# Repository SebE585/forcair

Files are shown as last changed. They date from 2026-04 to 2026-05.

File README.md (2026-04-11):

# Forcair

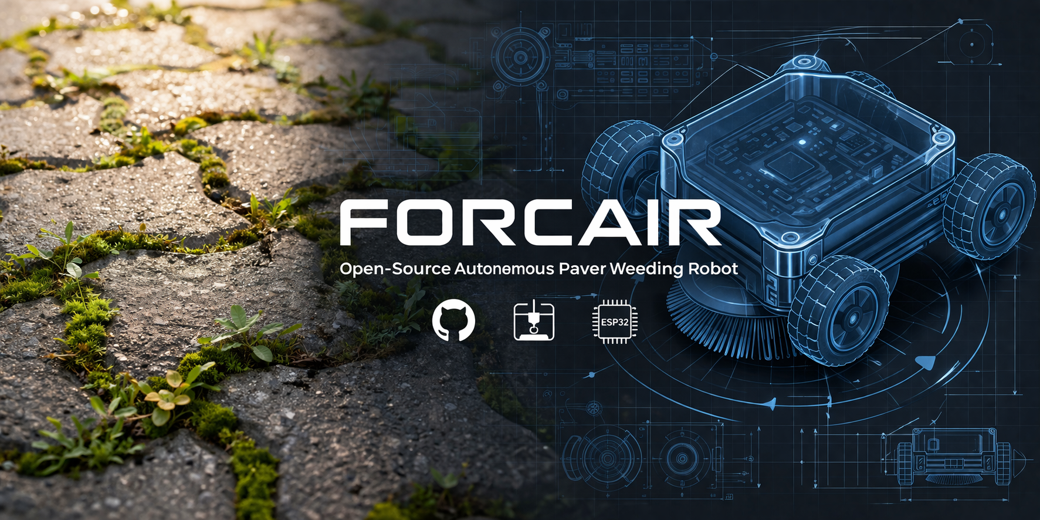
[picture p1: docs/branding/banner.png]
Forcair Banner


**The open-source robot that cleans your patio while you relax.**

Forcair is a low-cost, open-source autonomous robot that removes moss and weeds from paved surfaces using a rotating brush and computer vision.

Built with aluminum extrusion profiles, 3D printed parts, and an ESP32-CAM. Under 1.3 kg. ~150 EUR from scratch (or ~75 EUR if you reclaim motors + battery + brush motor from junk).

> Named after a vehicle from [*Jayce and the Wheeled Warriors*](https://en.wikipedia.org/wiki/Jayce_and_the_Wheeled_Warriors) (1985).

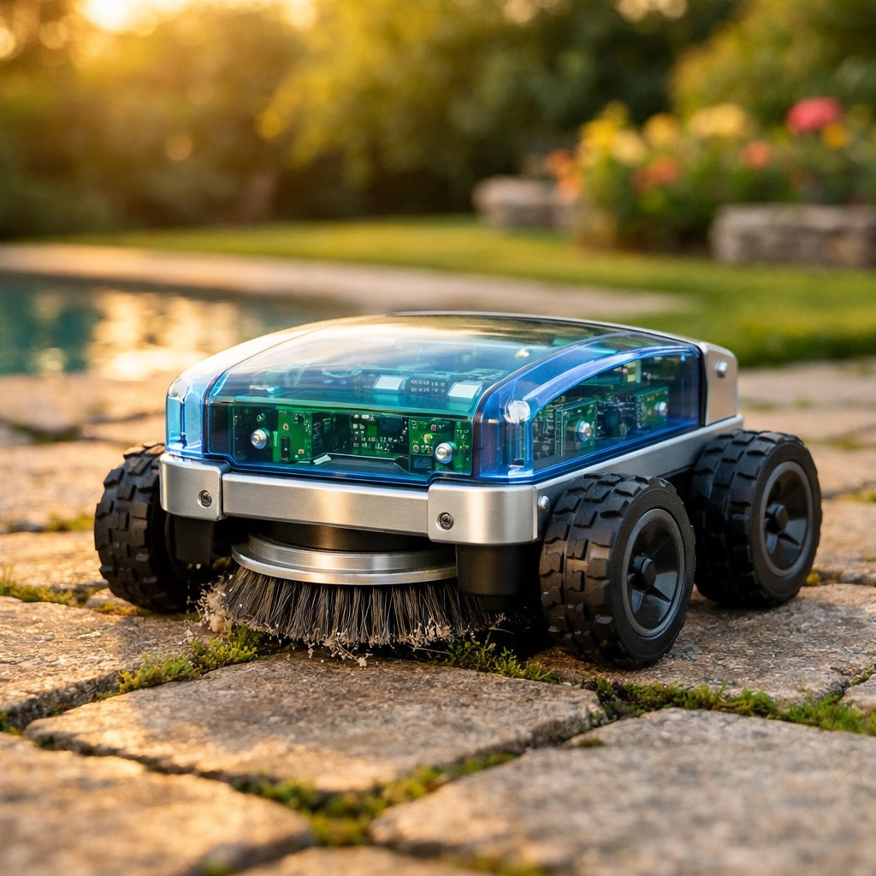
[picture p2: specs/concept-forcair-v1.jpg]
Concept


---

## The Problem

Interlocking pavers and stone patios accumulate **moss and weeds** in their joints. Existing solutions:

| Solution | Cost | Effort | Eco-friendly |
|---|---|---|---|
| Manual scraping | 0 EUR | Hours on your knees | Yes |
| Pressure washer | 200+ EUR | Heavy, damages joints | Wastes water |
| Chemical herbicide | 10 EUR/year | Easy | **No** |
| Commercial robot mower | 1000+ EUR | N/A on pavers | N/A |
| **Forcair** | **~150 EUR** (or ~75 EUR with reclaimed parts) | **Autonomous** | **Yes** |

## How It Works

| Step | What | How |
|---|---|---|
| **1. Detect** | ESP32-CAM sees green moss on gray pavers | HSV color thresholding (no cloud, on-device) |
| **2. Navigate** | Bump & turn — or systematic sweep on ~150 m² | Phase 1.5 reactive → Phase 2 IMU dead reckoning → Phase 3 GPS RTK |
| **3. Clean** | Rotating brush scrubs the joint | Nylon or steel wire, ~50 mm disc, drill-style attachment |

The robot patrols your patio autonomously. When the camera detects green moss, it lowers the rotating brush and scrubs the joint clean. Simple, mechanical, effective.

## Specifications

| Parameter | Value |
|---|---|
| Dimensions | 300 x 250 x 100 mm |
| Weight | ~1.3 kg |
| Frame | Aluminum 2020 extrusion profiles |
| Wheels | 4x 80mm (PETG hub + TPU tire), 4WD |
| Brain | ESP32-CAM (camera + WiFi + GPIO) |
| Motor driver | L298N dual H-bridge (2 A/ch, PWM + IN1/IN2) ×2 |
| Brush | Rotary nylon or steel wire, 50mm, on Z-axis |
| Battery | 3S 18650 pack (11.1V), ~1h15 autonomy |
| Navigation | Bump & turn (Phase 1) → IMU dead reckoning (Phase 2) → GPS RTK (Phase 3) |
| Detection | HSV green-on-gray thresholding (inspired by [OWL](https://github.com/geezacoleman/OpenWeedLocator)) |
| Manufacturing | 3D printing (Bambu Lab X1C) + off-the-shelf parts |
| **Total cost** | **~150 EUR** from scratch, all-in (or ~75 EUR if you reclaim motors + battery + brush motor) — see [live BOM widget](https://sourcier.shop/bom/SebE585/forcair) |

## Project Status

| Phase | Status | Description |
|---|---|---|
| **Phase 0** | **In progress** | Manual brush testing (drill + brush on pavers) |
| Phase 1 | Planned | Wheeled base + ESP32-CAM scout + remote control |
| Phase 1.5 | Planned | Bump & turn by zones (~30m² per session) |
| Phase 2 | Future | Systematic sweep with IMU dead reckoning (MPU6050) for 150m² |
| Phase 3 | Future | GPS RTK (u-blox F9P + NTRIP) for full autonomous coverage |

## Build Your Own

### Bill of Materials (BOM)

The BOM is maintained as a machine-readable [`BOM.yaml`](BOM.yaml) at the root of this repo
and consumed by [sourcier.shop](https://sourcier.shop) to generate a live, always-up-to-date
sourcing widget with vendor links optimized per country.

> 🛒 **Live BOM widget:** [**sourcier.shop/bom/SebE585/forcair**](https://sourcier.shop/bom/SebE585/forcair)
>
> One click to see all 27 components, vendor matches (Motedis, AliExpress, Leroy Merlin…),
> per-line and total estimated cost, with country-aware vendor selection (FR/DE/UK/US).
> Supports `?lang=fr|en` for multilingual descriptions.

The BOM is organized in 5 supply lanes:

- **A — AliExpress**: electronics + small mechanical hardware (bearings, drivers, sensors, connectors, screws)
- **B — Motedis**: aluminum 2020 extrusion (custom-cut profiles, corner brackets, T-nuts)
- **C — Bambu Lab Store**: filament (PETG translucent blue dome + TPU 95A tires + PETG black chassis)
- **D — Hardware store / Brico**: plywood platform, drill brushes, PG7 cable glands, foam seals
- **E — Reclaimed from junk**: see table below — these items are not in the public BOM since they
  depend on what donors you can find locally

Need to add a vendor or update a price? Edit [`BOM.yaml`](BOM.yaml) and Sourcier will pick it up
within 1 hour (cache TTL). The BOM.yaml format spec is documented at
[sourcier.shop/spec/bom-yaml](https://sourcier.shop/spec/bom-yaml).

#### Reclaimed from junk — project-specific (not in BOM.yaml)

| Part | Source | Notes |
|---|---|---|
| 4× DC traction motors | Old inkjet printers | Canon MG6450, Epson XP-2150 |
| ESP32-CAM | Stock | Phase 1 brain |
| RPi Zero 2W | Stock | Phase 2 vision |
| GoPro Hero 3+ | Stock | Phase 2 mapping |
| 8 mm linear rods (Z-axis) | Old printers | 2× recovered |
| 12 V brush motor | Reclaimed vacuum (Telsa 80) | or ~5 EUR if no donor |
| 3S 18650 battery pack | Reclaimed Ryobi 36V | or ~15 EUR new pack |
| Springs (Z-axis return) | Old printers | Multiple |

#### 3D printed parts — free (you supply filament from supply lane C)

| Part | Material | Print time | Notes |
|---|---|---|---|
| 4× wheel hubs | PETG black | ~1 h each | 608ZZ housing |
| 4× tires | TPU 95A black | ~45 min each | Striped tread |
| 4× motor mounts | PETG black | ~30 min each | 2020 cradle |
| Brush Z-axis carriage | PETG black | ~2 h | IMS-002 |
| 2× linear bearings | PETG black | ~15 min each | 8 mm rods |
| **Dome cover** | **PETG translucent blue** | ~3 h | The signature shell, PCBs visible through |
| ESP32-CAM mount | PETG black | ~15 min | + tilt adjustment |
| Brush confinement skirt | TPU 95A black | ~45 min | Soft seal under chassis |
| Front bumper | TPU 95A black | ~30 min | Integrates micro-switches |
| IR sensor mount (front) | PETG black | ~15 min | |
| 2× cliff sensor mounts | PETG black | ~10 min each | |

### Total budget (Phase 1.5 functional)

| Lane | Cash |
|---|---|
| A — AliExpress (electronics + mechanical) | ~55 EUR |
| B — Motedis (custom-cut extrusion) | ~20 EUR |
| C — Bambu Lab (filament dedicated to Forcair) | ~30 EUR |
| D — Brico (plywood, brushes, seals, PG7) | ~18 EUR |
| E — Reclaimed parts | 0 EUR |
| Shipping & misc | ~10 EUR |
| **Total cash, all-in** | **~135-155 EUR** |
| Total saved by reclaiming (vs new) | ~50 EUR |

The original "<75 EUR" target on the project banner refers to the bare-minimum Phase 1
electronics-only build assuming all reclaimable parts are available (motors, battery, brush motor,
linear rods). Real-world cost for a from-scratch build sits closer to **~150 EUR** including
filament and shipping. See the live [Sourcier widget](https://sourcier.shop/bom/SebE585/forcair)
for the up-to-date estimate based on current vendor prices.

### CAD Files

All mechanical parts are parametric, written in [CadQuery](https://cadquery.readthedocs.io/) (Python).
STEP and STL exports are provided for direct slicing.

```
hardware/cad/
├── assembly_chassis.py      # Full assembly visualization
├── wheel_hub.py             # PETG wheel hub (WH-001)
├── wheel_tire.py            # TPU tire (WT-001)
├── motor_mount.py           # Motor cradle for 2020 profile
├── ims_plate.py             # Interchangeable Module Standard plate
├── mod002_brosse.py         # Rotating brush module (MOD-002)
├── esp32_cam_mount.py       # ESP32-CAM bracket with tilt
├── capot_dome.py            # Protective dome (PETG translucent blue)
├── step/                    # STEP exports
└── stl/                     # STL exports (ready to print)
```

### Printing Guide

| Part | Material | Infill | Pattern | Perimeters | Layer | Time |
|---|---|---|---|---|---|---|
| Wheel hubs (x4) | PETG | 40% | gyroid | 4 | 0.2mm | ~45min each |
| Tires (x4) | TPU 95A | 20% | gyroid | 3 | 0.2mm | ~40min each |
| Motor mounts (x4) | PETG | 40% | gyroid | 4 | 0.2mm | ~25min each |
| Dome cover | PETG (translucent blue) | 15% | gyroid | 3 | 0.2mm | ~3h |
| All other parts | PETG | 30-40% | gyroid | 3 | 0.2mm | varies |
| **Total Phase 1** | | | | | | **~10-11h** |

**Why not 100% infill on wheels and tires?**

- **Wheel hubs (PETG, 40% gyroid)** — for a 1.3 kg robot (~330 g per wheel), radial and torsional loads are carried by the perimeters, not the infill. 4 walls + 40% gyroid is plenty; 100% just wastes filament and print time without measurable benefit.
- **Tires (TPU 95A, 20% gyroid)** — the whole point of TPU is compliance (grip + shock absorption). Printing TPU at 100% gives a *rigid* rubber tire with no give, which actively defeats the purpose: less grip on uneven pavers, more vibration into the chassis. 15-25% gyroid keeps the tire deformable enough to conform to joints while staying durable.

## Research & State of the Art

See [`research/state-of-the-art.md`](research/state-of-the-art.md) for a comprehensive literature review covering:

- 12+ similar DIY/open-source projects analyzed
- 24 scientific papers reviewed
- Validation of the rotating brush approach on hard surfaces ([Rask & Kristoffersen 2007](https://doi.org/10.1111/j.1365-3180.2007.00579.x))
- Identified gap: **no published work on autonomous robotic weeding for domestic paved surfaces**

Key references:
- [OpenWeedLocator (OWL)](https://github.com/geezacoleman/OpenWeedLocator) - green-on-brown detection algorithm we adapt to green-on-gray
- [Tertill](https://tertill.com/) (discontinued) - bump & turn navigation validated for small surfaces
- [LIAM-ESP](https://github.com/trycoon/liam-esp) - ESP32 navigation code reference

## Modular Tool System (IMS)

Forcair uses an **Interchangeable Module Standard** (IMS) interface — a single 100×80 mm plate
with a fixed mechanical and electrical pinout. Modules clip on tool-free in ~30 seconds.

**IMS Plate spec** (100 × 80 mm):

| Feature | Spec | Purpose |
|---|---|---|
| Fixation | 2× M5 butterfly bolts | Tool-free swap in ~30 s |
| Alignment | 2× centering posts, ⌀ 8 mm | Repeatable positioning |
| Power | XT60 connector | 12 V, 10 A continuous |
| Signal | JST-XH 3-pin | PWM control + ground |

| Module | Function | Status |
|---|---|---|
| MOD-002 | Rotating brush (nylon/steel) | Phase 1.5 |
| MOD-001 | Camera scout (GoPro) | Phase 2 |
| MOD-003 | Spray (water or anti-moss) | Future |
| MOD-004 | Leaf blower | Future |

Design your own module! The IMS plate CAD file is in `hardware/cad/ims_plate.py`.

## Architecture

**Phase 1.5 — ESP32-CAM only** (~150 EUR from scratch / ~75 EUR with reclaimed parts):

```mermaid
graph LR
    Phone["📱 Smartphone<br/>(monitoring)"]
    ESP["ESP32-CAM<br/>OV2640 + HSV detect<br/>GPIO control"]

    Sensors["2× Sharp IR (front)<br/>2× TCRT5000 (cliff)<br/>2× microswitch (bumper)<br/>1× piezo buzzer"]
    Servo["SG90 servo<br/>(Z-axis brush lift)"]
    Traction["2× L298N H-bridge<br/>↓<br/>4× DC motors"]
    Brush["IRLZ44N MOSFET<br/>↓<br/>12 V brush motor"]

    Phone <-. WiFi .-> ESP
    ESP --> Sensors
    ESP --> Servo
    ESP --> Traction
    ESP --> Brush
```

**Phase 2** (+2 EUR) — add an MPU6050 IMU for dead-reckoning navigation, enabling systematic
line sweeps over ~150 m².

**Phase 3** (+40 EUR) — add a u-blox F9P GPS-RTK receiver with NTRIP corrections for
centimeter-level outdoor positioning and full coverage planning.

## Contributing

Contributions welcome! Here's how you can help:

- **Build one** and share your results (especially with different paver types)
- **Improve the firmware** (ESP32 Arduino or ESP-IDF)
- **Design new modules** for the IMS interface
- **Test different brushes** and document effectiveness vs. joint wear
- **Translate** documentation
- **Report issues** or suggest improvements

## License

- **Hardware** (CAD, mechanical design): [CERN-OHL-S v2](LICENSE-HARDWARE)
- **Software** (firmware, scripts): [MIT](LICENSE-SOFTWARE)
- **Documentation**: [CC BY-SA 4.0](https://creativecommons.org/licenses/by-sa/4.0/)

## Related Projects

Forcair is part of a family of DIY projects, all named after vehicles from *Jayce and the Wheeled Warriors*:

| Project | Description |
|---|---|
| **Forcair** | Autonomous paver weeding robot (this project) |
| Vrillair | DIY CNC machine |
| Blindair | Modular workshop storage boxes |
| Depistair | Reclaimed parts inventory & shared BOM |

## Acknowledgments

- [OpenWeedLocator](https://github.com/geezacoleman/OpenWeedLocator) for the green-on-brown detection approach
- [Tertill](https://tertill.com/) (Franklin Robotics) for proving bump & turn works
- [LIAM-ESP](https://github.com/trycoon/liam-esp) for ESP32 navigation patterns
- The scientific work of Rask & Kristoffersen (2007) and Cauwer et al. (2014) on non-chemical weed control on hard surfaces

---

*Forcair is a personal open-source project. Not affiliated with any company.*

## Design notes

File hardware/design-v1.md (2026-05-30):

# Forcair - Design Chassis v1.2

> Plateforme robotique modulaire d'exterieur pour entretien des paves.
> Version : v1.2 - 2026-04-17 (guides Z flex Ø6/Ø8 + axes roue explicites)
> Version precedente : v1.1 - 2026-04-03
> Image concept : `../specs/concept-forcair-v1.jpg`
> Etat de l'art : `../research/state-of-the-art.md`

## 0. Architecture modulaire

Forcair est une **plateforme** (base roulante + electronique + vision) sur laquelle
se montent des **modules outils** interchangeables via une interface standard.

```
         PLATEFORME FORCAIR (base commune)
    ┌──────────────────────────────────────────┐
    │  Chassis 2020 + 4WD + ESP32 + RPi + Bat  │
    │  Navigation + Vision + WiFi              │
    └─────────────────────┬────────────────────┘
                          │
                 Interface Module Standard
                 (2x vis papillon M5 + XT60)
                          │
        ┌─────────────────┼─────────────────┐──── ...
        │                 │                 │
   ┌────┴────┐      ┌─────┴─────┐     ┌────┴────┐
   │ MOD-001 │      │  MOD-002  │     │ MOD-003 │
   │ CAMERA  │      │  BROSSE   │     │  SPRAY  │
   │ SCOUT   │      │ ROTATIVE  │     │         │
   │         │      │           │     │ Jet eau │
   │ Carto + │      │ Mousse /  │     │ ou anti │
   │ inspect │      │ herbes    │     │ mousse  │
   │         │      │           │     │         │
   │ Phase 1 │      │ Phase 2   │     │ Futur   │
   └─────────┘      └───────────┘     └─────────┘
```

### Interface Module Standard (IMS)

L'interface entre la plateforme et les modules est le point cle de la modularite.
Elle se situe sur le **chariot Z** (mecanisme montee/descente).

```
     VUE DE FACE - Interface Module Standard

     ┌──────────── chariot Z ────────────┐
     │                                    │
     │  ⊙ vis papillon     vis papillon ⊙ │  ← M5, serrage a la main
     │       M5                  M5       │
     │                                    │
     │       ┌──── plot ────┐             │
     │       │  centrage    │             │  ← 2 plots de centrage (imprimes 3D)
     │       └──────────────┘             │     garantissent l'alignement
     │                                    │
     │    [XT60]        [JST-XH 3p]       │  ← connecteurs : alim + signal
     │    alim 12V      signal PWM        │
     │                                    │
     └────────────────────────────────────┘
               ↕ interchangeable ↕
     ┌────────────────────────────────────┐
     │         MODULE (ex: brosse)        │
     │                                    │
     │  ⊙ trou M5           trou M5 ⊙    │
     │       ┌──── trou ────┐             │
     │       │  centrage    │             │
     │       └──────────────┘             │
     │    [XT60]        [JST-XH 3p]       │
     │                                    │
     │         [outil]                    │
     └────────────────────────────────────┘
```

### Specs interface

| Parametre | Valeur | Notes |
|---|---|---|
| Fixation mecanique | 2x vis papillon M5 | Serrage/desserrage a la main, pas d'outil |
| Centrage | 2x plots diam 8mm | Imprimes 3D, positionnement reproductible |
| Alimentation | Connecteur XT60 | 12V, 10A max (suffisant pour moteur brosse) |
| Signal | Connecteur JST-XH 3 broches | PWM vitesse + GND + sens rotation |
| Dimensions plaque module | 100 x 80 mm | Standard pour tous les modules |
| Masse max module | 500g | Budget masse restant sur chariot Z |

### Catalogue modules (prevu)

| Ref | Nom | Contenu | Statut |
|-----|-----|---|---|
| MOD-001 | Camera Scout | GoPro Hero 3+ sur support orientable | Phase 1 |
| MOD-002 | Brosse Rotative | Moteur Telsa 80 + brosse nylon | Phase 2 |
| MOD-003 | Spray | Pompe 12V + reservoir + buse | Futur |
| MOD-004 | Souffleur | Ventilateur 12V centrifuge | Futur |
| MOD-005 | Balai | Brosse douce large | Futur |

## 1. Contraintes terrain

Donnees extraites des photos (`specs/photos/`) :

| Contrainte | Valeur | Impact design |
|---|---|---|
| Type paves (terrasse) | Autobloquants, joints ~10mm | Roues > 60mm diam, pas trop fines |
| Type dalles (allee) | Carrees ~30x30cm, joints ~8mm | Surface plus reguliere |
| Mousse | Dans les joints, epaisseur 2-5mm | Brosse doit atteindre le fond du joint |
| Denivele joints | 3-8mm entre paves | Suspension ou roues souples |
| Surface totale | **~150m2** (terrasse + allees + abords piscine) | Navigation par zones ou systematique necessaire |
| Environnement | Exterieur, humidite, soleil | Electronique protegee |
| Obstacles | Bordures pierre, pieds de table, mur | Detection ou bumper |

## 2. Dimensions generales

```
     VUE DE DESSUS (cotes en mm)

     ←──────── 300 ─────────→

  ↑  ┌─profilé 2020─────────────profilé 2020─┐
  │  │                                        │
  │  │  ┌──────────────────────────────────┐  │
     │  │          ZONE ELECTRONIQUE       │  │
 250 │  │  [ESP32-CAM]       [RPi Zero 2W] │  │
     │  │  [Motor driver]    [Batterie 3S] │  │
  │  │  └──────────────────────────────────┘  │
  │  │                                        │
  │  │  ┌──────────────────────────────────┐  │
  ↓  │  │          ZONE ACTIONNEUR         │  │
     │  │  [Moteur brosse]   [Mecanisme Z] │  │
     │  └──────────────────────────────────┘  │
     └────────────────────────────────────────┘
    ◯roue AR-G                        roue AR-D◯

    ◯roue AV-G                        roue AV-D◯
```

| Parametre | Valeur | Justification |
|---|---|---|
| Longueur (X) | 300 mm | Couvre 2-3 paves en largeur |
| Largeur (Y) | 250 mm | Stabilite + place pour electronique |
| Hauteur chassis | ~100 mm | Garde au sol ~30mm + plateau + composants |
| Garde au sol | 30 mm | Passer les irregularites entre paves |
| Poids cible | < 2.5 kg | Moteurs recup DC suffisants |
| Empattement roues | 260 x 210 mm | Stabilite sur surface irreguliere |

## 3. Structure chassis

### 3.1 Cadre en profiles 2020

```
     VUE DE DESSUS - CADRE

     ┌═══════════════════════════════════┐
     ║           traverse AV            ║  ← profilé 250mm
     ╠═══════════════════════════════════╣
     ║                                   ║
     ║  longueur G          longueur D   ║  ← profilés 300mm
     ║                                   ║
     ╠═══════════════════════════════════╣
     ║           traverse AR            ║  ← profilé 250mm
     └═══════════════════════════════════┘

     Assemblage : 4x equerres 20x20 Motedis (1 par angle)
```

**Decoupe dans les barres Motedis 1m :**
- Barre 1 : 300 + 300 + 250 + 100(reste) = 1 barre
- Barre 2 : 250 + reste pour Vrillair

**Fixation equerres :** ecrou marteau M4 + vis M4x8 (kit Motedis)

### 3.2 Plateau

Le plateau se fixe sur les profiles via T-nuts M5.

| Option | Materiau | Epaisseur | Poids | Waterproof | Recommandation |
|---|---|---|---|---|---|
| A | Contreplaque | 5mm | ~150g | Non (vernis possible) | **Proto Phase 1** |
| B | **PETG noir imprime** | 2-3mm | ~120g | Oui | **Version finale** (cf image concept) |
| C | Plaque inox Silvercrest | 1-2mm | ~200g | Oui | Alternative (decoupe necessaire) |
| D | Polypropylene alveolaire | 4mm | ~50g | Oui | Trop souple seul |

**Phase 1 : contreplaque 5mm** (280 x 230 mm), perce aux emplacements T-nuts.
**Version finale : PETG noir** imprime en plusieurs pieces, assemblee par clips/vis.

### 3.3 Protection electronique / Carrosserie

> Ref visuelle : `../specs/concept-forcair-v1.jpg`
> Objectif : capot translucide bleu laissant voir les PCB (effet "tech visible").

L'electronique doit etre protegee (usage exterieur, projections d'eau/mousse).

```
     VUE DE COTE - CAPOT

          ┌──capot PETG imprime──┐
          │                      │
     ─────┤   [electronique]     ├─────  plateau
          │                      │
          └──────────────────────┘
```

**Phase 1 (proto) :**
- Capot imprime en PETG gris/naturel
- Fixation par clips sur le plateau (pas de vis = demontage rapide)
- Ouvertures pour ventilation (labyrinthes anti-projection)
- Passage cables etanches vers moteurs (presse-etoupes ou silicone)

**Version finale (cf image concept) :**
- **Capot en PETG bleu translucide** : les PCB vertes (ESP32-CAM, RPi) sont visibles a travers
- Forme arrondie type dome (rayon de courbure ~120mm)
- Bandeau alu visible au milieu (profile 2020 = element esthetique)
- Joint silicone entre capot et plateau pour etancheite
- LED status visible a travers le capot (optionnel)
- **Filament** : PETG bleu translucide (eSUN, Polymaker, ou Bambu Lab) ~25 EUR/bobine

## 4. Roues et traction

### 4.1 Conception roues

```
     VUE EN COUPE ROUE (diam 80mm)

     ┌─────────────────────────┐
     │ ░░░ Pneu TPU 95A ░░░░░ │  8mm epaisseur
     │ ░ ┌─────────────────┐ ░ │
     │ ░ │  Moyeu PETG     │ ░ │
     │ ░ │                 │ ░ │
     │ ░ │    ┌───────┐    │ ░ │
     │ ░ │    │ 608ZZ │    │ ░ │  roulement 8x22x7mm
     │ ░ │    │  ⊕    │    │ ░ │  axe 8mm
     │ ░ │    └───────┘    │ ░ │
     │ ░ │                 │ ░ │
     │ ░ └─────────────────┘ ░ │
     │ ░░░░░░░░░░░░░░░░░░░░░░ │
     └─────────────────────────┘
            ←── 80mm ──→
```

| Piece | Materiau | Impression | Parametres cles |
|---|---|---|---|
| Moyeu | PETG | Bambu Lab, 0.2mm layer | Logement 608ZZ (22mm ext), fixation axe |
| Pneu | TPU 95A | Bambu Lab, 0.2mm layer | Epaisseur 8mm, profil strie pour grip |

**Profil du pneu :** stries transversales pour grip sur paves humides + mousse.

```
     Surface du pneu (deroulee)
     ═══╗  ╔═══╗  ╔═══╗  ╔═══
        ╚══╝   ╚══╝   ╚══╝
     Stries 2mm profondeur, pas 5mm
```

### 4.2 Motorisation traction

**Config : 4WD (4 roues motrices)**

Chaque roue est entrainee par un moteur DC recup.

| Moteur | Source recup | Tension | Usage |
|---|---|---|---|
| 2x moteurs DC (chariot) | Canon MG6450 + Epson XP-2150 | 5-12V | Roues AV |
| 2x moteurs DC | Ancienne imprimante (boite recup) | 5-12V | Roues AR |

**Si les moteurs recup sont trop faibles** (couple insuffisant sur paves) :
- Fallback : 4x moteurs N20 12V 200RPM (~10 EUR les 4 sur AliExpress)
- Ou 4x moteurs GA12-N20 avec reducteur metal

### 4.3 Fixation moteurs sur profiles

```
     VUE DE DESSOUS

     ┌══════════════════════════════════┐  profil 2020
     │  ┌──────┐              ┌──────┐ │
     │  │MotAVG│              │MotAVD│ │  supports moteur
     │  │  ◯───┼──axe────────┼───◯  │ │  imprimes 3D
     │  └──┼───┘              └───┼──┘ │  fixes par T-nuts
     │     │                      │    │
     │   roue                   roue   │
     │   AV-G                   AV-D   │
     │                                 │
     │  ┌──────┐              ┌──────┐ │
     │  │MotARG│              │MotARD│ │
     │  │  ◯───┼──axe────────┼───◯  │ │
     │  └──┼───┘              └───┼──┘ │
     │     │                      │    │
     │   roue                   roue   │
     │   AR-G                   AR-D   │
     └══════════════════════════════════┘
```

**Support moteur** : piece imprimee 3D (PETG) en forme de U.
- Se fixe sous le profile 2020 via 2x T-nuts M5
- Collier ou berceau ajuste au diametre du moteur recup
- Conception parametrique (CadQuery) : adaptable a chaque moteur

**Transmission moteur → roue :**
- Coupleur d'arbre rigide (axe moteur Ø5 → axe roue Ø8 qui traverse le 608ZZ)
- Ou impression 3D d'un engrenage si reduction necessaire

**Axes roue (BOM explicite) :**

| Piece | Quantite | Spec | Source |
|---|---|---|---|
| Axes roue | 4 | **Ø8mm, longueur ~60mm** (obligatoire Ø8 : impose par ID 608ZZ) | 1 tige recup imprimante Ø8 de ~300mm coupee en 4 segments |

## 5. Systeme modulaire (actionneur)

> Tous les outils se montent sur l'Interface Module Standard (IMS) du chariot Z.
> Voir section 0 pour les specs de l'interface.

### 5.1 MOD-002 : Brosse rotative (premier module)

```
     VUE DE FACE - MODULE BROSSE sur IMS

     ══════════ plateau ══════════
           │              │
     ──────┤  chariot Z    ├──────  guides lineaires
     tige  │              │  tige  (recup imprimante)
     lisse │  ┌─── IMS ──┐│  lisse
           │  │⊙M5    M5⊙││
           │  │ [XT60]    ││
           │  └─────┬─────┘│
           │  ======╪====== │  ← decrochage rapide
           │  ┌─────┴─────┐│
           │  │  MOD-002   ││
           │  │ [Moteur    ││
           │  │  Telsa 80] ││
           │  │    │       ││
           │  │ ┌──┴──┐   ││
           │  │ │BROSSE│   ││
           │  │ │nylon │   ││
           │  │ └─────┘   ││
           │  └────────────┘│
           ▼                ▼
     ▓▓▓▓▓▓▓▓▓▓▓▓▓▓▓▓▓▓▓▓▓▓▓▓▓  paves
```

| Composant | Spec | Source |
|---|---|---|
| Plaque module | 100x80mm, PETG imprime, 2x trous M5 + plots centrage | Impression 3D |
| Moteur brosse | DC 12.6V 1A (Telsa 80) | Recup |
| Connecteur alim | XT60 male | Achat (~1 EUR) |
| Connecteur signal | JST-XH 3p male | Achat (~0.50 EUR) |
| Brosse | Nylon dur, disque ou coupe diam ~60mm | Brico (~5 EUR) |
| Vitesse rotation | ~1000-3000 RPM (a tester Phase 0) | - |

### 5.1b MOD-001 : Camera Scout (Phase 1)

| Composant | Spec | Source |
|---|---|---|
| Plaque module | 100x80mm, PETG, 2x trous M5 | Impression 3D |
| GoPro Hero 3+ | Sur support orientable (tilt) | Stock |
| Servo inclinaison | SG90 (optionnel) | Achat (~2 EUR) |
| Connecteur | JST-XH (signal servo) | - |

### 5.2 Mecanisme montee/descente (axe Z)

La brosse doit pouvoir :
- **Descendre** : contact avec le joint du pave (~20mm de course)
- **Monter** : position haute quand le robot se deplace sans nettoyer

**Guidage lineaire recup imprimante :**

```
     Mecanisme Z (vue de cote)

     ═══════ plateau ═══════
         │             │
    tige lisse     tige lisse    ← recup imprimante (Ø6 ou Ø8, L=80-120mm)
         │             │
     ┌───┴─────────────┴───┐
     │   chariot mobile     │    ← palier imprime 3D (ou LM8UU)
     │   ┌─── IMS ───┐     │    ← Interface Module Standard
     │   │⊙M5    M5⊙ │     │       2x vis papillon + XT60 + JST
     │   └─────┬──────┘     │
     │   ======╪======      │    ← le module se clipse ici
     │   ┌─────┴──────┐     │
     │   │  MODULE     │     │
     │   └─────────────┘     │
     └──────────┬───────────┘
                │
         ressort rappel          ← recup imprimante (position haute par defaut)
                │
                ▼
     Position basse = nettoyage
```

| Piece | Source | Notes |
|---|---|---|
| 2x tiges lisses Ø6 ou Ø8 | Recup imprimante (chariot coupe) ou AliExpress | **Longueur 80-120mm** (pas 200-300mm : hauteur chassis = 100mm) |
| 2x paliers lineaires | Imprimes 3D PETG **parametriques** (diametre en variable) ou LM6UU/LM8UU recup | Glissement sur tiges. Le script CAD prend le Ø en parametre. |
| 1x ressort de rappel | Recup imprimante | Position haute par defaut |
| Course Z | ~20-25mm | Suffisant pour atteindre fond joint |

**Choix Ø6 vs Ø8 :** pas de contrainte mecanique sur 20-25mm de course. Ø6 preferable si tu as stock recup en Ø6 (frequent sur imprimantes jet d'encre). Ø8 si deja dispo. Ø8 est **obligatoire cote roues** (roulement 608ZZ impose l'ID 8mm).

**Actionnement Z :**
- **Phase 1 (simple)** : servo SG90 + came (5 EUR si achat)
- **Phase 2 (precis)** : moteur pas-a-pas recup + vis sans fin

## 6. Electronique

### 6.1 Architecture (v1.1 simplifiee)

> **Changement v1.1** : la recherche (R02, R03) montre que l'ESP32-CAM suffit pour
> la detection HSV et meme du CNN leger. Le RPi Zero 2W est reporte a Phase 2.
> Un seul processeur = un seul firmware, pas de communication inter-processeurs.

```
     Architecture Phase 1 (ESP32-CAM seul)

     ┌─────────────┐     WiFi      ┌──────────────┐
     │  ESP32-CAM  │◄────────────►│ Mac/Smartphone│
     │             │               │ (monitoring)  │
     │ OV2640 cam  │               │ (telecommande)│
     │ HSV detect  │               └──────────────┘
     │ GPIO control│
     │ WiFi AP/STA │
     └──┬───┬──┬───┘
        │   │  │
   ┌────┘   │  └────────┐
   │        │           │
┌──┴────┐ ┌─┴───┐ ┌────┴────────┐
│TB6612 │ │Servo│ │Capteurs     │
│FNG    │ │ Z   │ │ 2x IR Sharp │
│(MOSFET│ │     │ │ 2x bumper   │
│driver)│ └─────┘ │ 1x buzzer   │
└┬──┬───┘         │ (1x tension)│
 │  │             └─────────────┘
4x moteurs DC
+ moteur brosse (via MOSFET)
```

> **Phase 2 (si necessaire)** : ajouter RPi Zero 2W pour SLAM, cartographie,
> ou ML avance. L'ESP32-CAM passe en controleur bas-niveau.

### 6.2 Composants

| Composant | Modele | Source | Role |
|---|---|---|---|
| Processeur principal | **ESP32-CAM** | Stock | Camera OV2640, detection HSV, WiFi, GPIO, controle temps reel |
| Driver traction | **TB6612FNG** (double pont H MOSFET) | Achat ~3 EUR | 4 moteurs DC (2 canaux, G+D en parallele). Remplace L298N. |
| Driver brosse | MOSFET IRLZ44N + diode flyback | Recup ou ~1 EUR | Commutation moteur brosse 12V (PWM depuis ESP32) |
| Capteurs obstacle | 2x Sharp GP2Y0A21 (IR 10-80cm) | Achat ~2 EUR | Detection obstacles a distance (murs, pieds de table) |
| Capteurs contact | 2x micro-switch + bumper TPU | Recup ou ~1 EUR | Detection contact (bordures, murs) |
| Retour sonore | Buzzer piezo passif | Achat ~0.30 EUR | Batterie faible, obstacle, fin de mission |
| Monitoring batterie | Pont diviseur resistif sur ADC ESP32 | Composants recup | Tension batterie en temps reel, coupure si < 9.6V (3.2V/cellule) |
| Alimentation | Pack 3S 18650 (11.1V) | Recup Ryobi ou achat | Tout le robot |

> **Composants en reserve (Phase 2)** : RPi Zero 2W (stock), GoPro Hero 3+ (stock),
> module GPS NEO-6M (~3 EUR), LiDAR low-cost (~20 EUR).

**Pourquoi TB6612FNG au lieu de L298N :**

| Critere | L298N | TB6612FNG |
|---|---|---|
| Technologie | BJT (bipolaire) | **MOSFET** |
| Chute de tension | **~2V** (perte enorme sur 11.1V) | **~0.5V** |
| Rendement | ~70% | **~95%** |
| Dissipation thermique | Chauffe, necessite radiateur | Froid |
| Taille | 43x43mm | **20x20mm** |
| Prix | ~3 EUR | ~3 EUR |
| Courant max/canal | 2A | 1.2A (suffisant pour moteurs recup) |

> Source : communaute DIY robotique (LIAM-ESP, RoboFoundry). Le L298N est un
> heritage des annees 2000, le TB6612FNG est le standard actuel pour les petits robots.

### 6.3 Alimentation

**Pack 3S (11.1V nominal, 12.6V charge) :**

```
     Batterie 3S
     ┌─────────────────┐
     │ [18650] [18650]  │  si recup Ryobi : 2P par cellule (4Ah)
     │ [18650] [18650]  │  sinon : 1P (2Ah, suffisant proto)
     │ [18650] [18650]  │
     │      [BMS 3S]    │  protection charge/decharge
     └────────┬─────────┘
              │ 11.1V
         ┌────┼────────────┐
         │    │            │
    ┌────┴──┐ │       ┌────┴───┐
    │ Buck  │ │       │ Direct │
    │ 5V 2A │ │       │ 11.1V  │
    └───┬───┘ │       └───┬────┘
        │     │           │
    ESP32-CAM │      Moteurs DC
    + servo   │      + moteur brosse
    + capteurs│
              │
         ┌────┴───────┐
         │ Pont div.  │  → ADC ESP32 (GPIO 34/35)
         │ R1=100k    │  Vmesure = Vbat * R2/(R1+R2)
         │ R2=33k     │  11.1V → ~2.75V (safe pour ADC 3.3V)
         └────────────┘
```

> **Changement v1.1** : ajout monitoring tension batterie. Le BMS protege la batterie,
> mais sans monitoring le robot ne sait pas quand rentrer ou biper.
> Seuils : < 10.5V = bip avertissement, < 9.6V = arret moteurs + bip continu.

**Si cellules Ryobi HS :** achat 6x 18650 (~12 EUR) ou pack LiPo 3S RC (~15 EUR).

**Autonomie estimee (revisee v1.1) :**
- Moteurs traction : 4x 0.5A = 2A
- Moteur brosse : 1A
- Electronique (ESP32-CAM seul + capteurs) : **0.25A** (vs 0.5A avec RPi)
- Total : **~3.25A** → avec pack 4Ah = **~1h15 d'autonomie** (+15min vs v1)

## 7. Logiciel (apercu)

### 7.1 Phase 1 - Scout + telecommande

> **Changement v1.1** : tout tourne sur ESP32-CAM seul.

| Module | Plateforme | Fonction |
|---|---|---|
| Stream video | ESP32-CAM | Flux MJPEG WiFi vers Mac/smartphone |
| Detection mousse | **ESP32-CAM** | Seuillage HSV (vert sur gris) directement sur l'ESP32 (cf. R01 OWL) |
| Telecommande | Mac/smartphone | Pilotage WiFi (webapp simple) |
| Capteurs | ESP32 GPIO | IR distance + bumpers → evitement reactif |
| Monitoring | ESP32 ADC | Tension batterie → bip si faible |

### 7.2 Phase 1.5 - Nettoyeur semi-autonome (bump & turn par zones)

> **v1.1** : phase intermediaire inspiree de Tertill. Le robot patrouille
> seul en mode "random walk" et brosse quand il detecte du vert.
>
> **v1.2** : surface corrigee a ~150m2. Le bump & turn seul ne couvre pas
> 150m2 en une charge (~1h15). Solution : **decoupe en zones manuelles**.
> L'utilisateur pose le robot dans une zone de ~30m2, le robot nettoie
> en bump & turn, puis l'utilisateur le deplace a la zone suivante.
> 5 zones x 30min = 150m2 en une journee (avec recharges).

| Module | Plateforme | Fonction |
|---|---|---|
| Navigation | ESP32 | **Bump & turn** (Tertill) : avancer, tourner sur obstacle. Couverture aleatoire par zone. |
| Detection mousse | ESP32-CAM | HSV vert-sur-gris → brosse ON si vert detecte |
| Controle Z | ESP32 | Servo descente brosse |
| Evitement obstacles | ESP32 | IR Sharp (anticipation) + bumpers (contact) |
| Securite | ESP32 | Monitoring batterie, arret si < 9.6V, tilt detection (MPU6050 optionnel) |

> **Limitation connue** : le bump & turn couvre ~95% d'une zone de 30m2 en ~45min.
> Pour 150m2 complets, il faut repositionner le robot manuellement entre les zones.
> C'est la raison principale de l'evolution vers la Phase 2 (navigation systematique).

### 7.3 Phase 2 - Navigation systematique (dead reckoning)

> A 150m2, le robot doit couvrir la surface methodiquement sans intervention humaine.
> Le dead reckoning (IMU + odometrie roues) permet un balayage en lignes paralleles.
> La derive est corrigee par recalage sur les murs/bordures (bumpers = reference connue).

| Module | Plateforme | Fonction |
|---|---|---|
| Navigation | ESP32 + **MPU6050** | Balayage en lignes paralleles, heading gyroscope, recalage bumpers |
| Odometrie | ESP32 | Comptage tours roues (encodeurs ou estimation temporelle) |
| Detection mousse | ESP32-CAM | HSV vert-sur-gris → brosse ON si vert detecte |
| Suivi de joints | ESP32-CAM | Detection lignes joints par vision (R12) → brossage cible |
| Securite | ESP32 + MPU6050 | Blocage, retournement, inclinaison excessive |

> **Cout supplementaire** : +2 EUR (MPU6050 sur AliExpress). Deja prevu en optionnel v1.1.

### 7.4 Phase 3 - Navigation RTK (precision centimetrique)

> Pour une couverture optimale de 150m2 sans intervention humaine, le GPS RTK
> offre une precision de ~2cm. Le reseau NTRIP francais (RGP, IGN) fournit
> les corrections gratuitement — pas besoin de base station.
> C'est la meme techno que le robot tondeuse Ecovacs Goat 800 RTK.

| Module | Plateforme | Fonction |
|---|---|---|
| Positionnement | **u-blox F9P** + antenne patch | GPS RTK via NTRIP (RGP IGN), precision ~2cm |
| Navigation | RPi Zero 2W | Planification de chemin, couverture systematique, zones exclues |
| Cartographie | RPi + GPS RTK | Carte de couverture, heatmap mousse, historique passages |
| Detection avancee | RPi + OWL | ML : classification mousse/herbe/lichen, segmentation |
| Verification | RPi + camera | Photo avant/apres passage, score de nettoyage |

> **Cout supplementaire** : ~40 EUR (F9P ~35 EUR + antenne ~5 EUR sur AliExpress).
> NTRIP gratuit en France. Pas de base station, pas de fil perimetrique.
> A ce stade, Forcair passe de prototype DIY a **vrai produit reproductible**.

## 8. Ce que nous n'avions pas anticipe (v1.1)

> Enseignements tires de l'etat de l'art (`../research/state-of-the-art.md`).
> Classe par criticite : CRITIQUE = doit etre traite avant Phase 1,
> IMPORTANT = Phase 1.5, NICE = Phase 2+.

### 8.1 CRITIQUE - Gestion des debris de brossage

**Probleme** : le design v1 ne dit pas **ou vont les debris** (mousse arrachee,
terre, petits cailloux). La brosse rotative projette les debris. Si non gere,
le robot re-salit la surface qu'il vient de nettoyer.

**Solutions observees dans les projets similaires :**

| Solution | Complexite | Efficacite | Retenue |
|---|---|---|---|
| Jupe de confinement (TPU souple autour de la brosse) | Faible | Moyenne | **Phase 1** |
| Aspiration (petit ventilateur + bac) | Moyenne | Haute | Phase 2 (= MOD-004 Souffleur inverse) |
| Brossage vers l'exterieur (sens de rotation oriente) | Nulle | Faible | Phase 1 (complementaire) |

**Action** : imprimer une jupe TPU souple autour de la zone brosse. La jupe confine
les debris. Le robot les pousse vers le bord de la terrasse par mouvement avant.

```
     VUE EN COUPE - JUPE DE CONFINEMENT

     ══════ plateau ══════
           │         │
     ──────┤ axe Z   ├──────
           │         │
      ┌────┴─────────┴────┐
      │  ┌─ MOD-002 ──┐   │
      │  │  [moteur]   │   │
      │  │  [brosse]   │   │
      ├──┘  ▓▓▓▓▓▓▓▓   └──┤  ← jupe TPU souple (~3mm)
      │    debris confines │    imprimee, clipee sous le chassis
      └────────────────────┘
     ▓▓▓▓▓▓▓▓▓▓▓▓▓▓▓▓▓▓▓▓▓▓  paves
```

**Cout** : ~1 EUR filament TPU. **Masse** : ~15g.

### 8.2 CRITIQUE - Etancheite electronique en usage exterieur

**Probleme** : le design v1 mentionne un capot mais pas de **classe IP**. La brosse
projette de l'eau, de la terre et de la mousse humide. L'ESP32-CAM et le driver
sont directement en dessous.

**Solutions observees :**
- **Tertill** : boitier scelle, connecteurs etanches, design IP67
- **LIAM-ESP** : boitier etanche avec presse-etoupes
- **ROMI** : compartiment electronique separe du compartiment outil

**Action Phase 1** :
- Separer electronique (haut, sous capot) et outil (bas, sous chassis) physiquement
- Joints en mousse adhesive entre capot et plateau (~1 EUR, Brico)
- Presse-etoupes PG7 pour les cables qui traversent le plateau (4x, ~2 EUR)
- Vernis conforme sur l'ESP32-CAM (spray silicone, ~3 EUR la bombe, recup atelier)
- Objectif : **IP44 minimum** (projections d'eau et particules)

**Cout** : ~3 EUR. **Masse** : ~10g.

### 8.3 CRITIQUE - Protection camera contre les projections

**Probleme** : la camera OV2640 de l'ESP32-CAM pointe vers le sol pour detecter
la mousse. La brosse rotative projette des debris **vers la camera**.

**Action** : vitre de protection en polycarbonate devant l'objectif. Decoupee dans
un emballage blister recup. Fixation sur le support ESP32-CAM existant.

**Cout** : 0 EUR (recup). **Masse** : ~2g.

### 8.4 IMPORTANT - Blocage et detection de panne

**Probleme** : aucun projet similaire ne fonctionne sans detection de blocage.
Le robot va se bloquer contre des obstacles (pieds de table, bordures en angle,
paves souleves). Sans detection, les moteurs forcent et grillent.

**Solutions observees :**
- **Tertill** : detection de courant moteur (stall = courant > seuil)
- **LIAM-ESP** : encodeurs sur roues + timeout
- **WEEDINATOR** : IMU pour detecter l'immobilite

**Action Phase 1** :
- Monitoring courant via mesure de tension sur resistance shunt (0.1 ohm) sur ADC ESP32
- Si courant > seuil pendant 2s → arreter moteurs, reculer, tourner 90-180 degres
- Optionnel Phase 1.5 : ajouter MPU6050 (IMU 6 axes, ~2 EUR) pour detecter :
  - Blocage (pas de mouvement malgre moteurs actifs)
  - Retournement (securite : arret immediat)
  - Inclinaison excessive (bord de terrasse, marche)

**Cout** : 0 EUR (shunt = resistance recup) ou ~2 EUR (MPU6050). **Masse** : ~3g.

### 8.5 IMPORTANT - Pression de brosse constante

**Probleme** : le design v1 utilise un servo SG90 + came pour l'axe Z. Mais le servo
maintient une **position** fixe, pas une **pression** constante. Si le pave est plus
haut ou plus bas que prevu, la brosse appuie trop ou pas assez.

**Solution observee (Aigamo, ROMI)** : pression par gravite ou ressort, pas par servo.

**Action revisee** :
- **Le ressort de rappel (recup) pousse la brosse VERS LE BAS** (inversement du v1 ou
  le ressort rappelait vers le haut)
- Le servo releve la brosse quand on ne veut PAS brosser (position haute = verrouillage)
- En mode brossage : le servo relache, le ressort + gravite appliquent une pression
  constante quel que soit le relief
- **Avantage** : le servo ne force pas en continu (economie batterie), et la pression
  s'adapte naturellement aux irregularites des paves

```
     AVANT (v1) :                    APRES (v1.1) :
     ressort ↑ (rappel haut)        ressort ↓ (pousse bas)
     servo ↓ (force vers bas)       servo ↑ (releve quand inactif)

     Servo fatigue en brossage       Servo au repos en brossage
     Pression variable               Pression constante par ressort
```

**Cout** : 0 EUR (meme composants, logique inversee). **Impact CAD** : modifier le
montage du ressort dans le mecanisme Z.

### 8.6 IMPORTANT - Navigation de bord de terrasse

**Probleme** : la terrasse a des **bords** (bordures, marches, pelouse). Le robot
doit detecter qu'il arrive au bord et ne pas tomber. Aucun capteur dans le design v1
ne gere ca.

**Solutions observees :**
- **Tertill** : bumper avant suffit (bordures surelevelees)
- **Tondeuses robot** : fil perimetrique enterre
- **Roomba** : capteurs cliff (IR pointant vers le sol)

**Action Phase 1** :
- 2x capteurs IR cliff (TCRT5000, ~0.50 EUR les 2) sous le chassis, avant
- Pointent vers le sol a ~45 degres vers l'avant
- Si pas de sol detecte (vide, herbe au lieu de paves) → arreter, reculer, tourner

**Cout** : ~0.50 EUR. **Masse** : ~2g.

### 8.7 NICE - Recharge et dock

**Probleme** : le design v1 suppose une recharge manuelle (debrancher la batterie).
Tous les robots commerciaux (Tertill, Ecovacs, Roomba) ont une solution de recharge
autonome.

**Pistes pour Phase 2** :
- **Contacts de charge** : 2 lames cuivre sur un dock, le robot se gare dessus (LIAM-ESP)
- **Panneau solaire** : petit panneau 5W sur le capot, recharge lente entre missions (Tertill, Acorn)
- **Induction Qi** : bobine sous le chassis, pad de charge au sol (~8 EUR)

**Pas d'action Phase 1** : recharge manuelle acceptee pour le prototype.

### 8.8 NICE - OTA (mise a jour firmware par WiFi)

**Probleme** : pour iterer rapidement, reflasher l'ESP32 par cable USB est penible
en exterieur. Tous les projets ESP32 matures implementent l'OTA.

**Action** : integrer ArduinoOTA ou ESP-IDF OTA dans le firmware des Phase 1.
Cout zero, juste du code. Permet de mettre a jour le robot depuis le WiFi terrasse.

### 8.9 Synthese des changements v1 → v1.1

| # | Sujet | v1 | v1.1 | Source |
|---|---|----|---|---|
| 1 | Processeur Phase 1 | RPi Zero 2W + ESP32-CAM | **ESP32-CAM seul** | R02, R03 |
| 2 | Motor driver | L298N | **TB6612FNG** | LIAM-ESP, RoboFoundry |
| 3 | Navigation Phase 1 | Balayage systematique | **Bump & turn** (Tertill) | Tertill, Aigamo |
| 4 | Capteurs obstacle | "Bumpers ou HC-SR04" (vague) | **2x IR Sharp + 2x bumper + 2x cliff** | Tertill, LIAM-ESP |
| 5 | Gestion debris | Non traite | **Jupe TPU confinement** | Observation terrain |
| 6 | Etancheite | Capot simple | **IP44 : joints mousse + presse-etoupes + vernis** | Tertill, LIAM-ESP |
| 7 | Pression brosse | Servo force vers bas | **Ressort pousse bas + servo releve** | Aigamo, ROMI |
| 8 | Monitoring batterie | Non traite | **Pont diviseur ADC + seuils alarme** | Standard robotique |
| 9 | Detection blocage | Non traite | **Shunt courant + optionnel MPU6050** | Tertill, LIAM-ESP |
| 10 | Protection camera | Non traite | **Vitre polycarbonate recup** | Bon sens |
| 11 | Detection bord terrasse | Non traite | **2x capteurs cliff TCRT5000** | Roomba, tondeuses |
| 12 | Brosse alternative | Nylon uniquement | **Nylon + acier doux (comparatif Phase 0)** | R13 (Rask) |
| 13 | Phase intermediaire | Phase 1 → Phase 2 | **Phase 1 → 1.5 (bump&turn) → 2** | Tertill |

## 9. Masses et equilibre

| Element | Masse v1 | Masse v1.1 | Position |
|---|---|---|---|
| Cadre profiles 2020 (4x) | ~250g | ~250g | Perimetre |
| Plateau contreplaque | ~150g | ~150g | Centre |
| 4x moteurs traction | ~200g | ~200g | Coins, sous le plateau |
| 4x roues (moyeu+pneu+roulement) | ~160g | ~160g | Coins |
| Moteur brosse (Telsa 80) | ~150g | ~150g | Centre-avant |
| Mecanisme Z + brosse | ~100g | ~100g | Centre-avant |
| Electronique (RPi+ESP32+driver) | ~50g | **~30g** (ESP32+TB6612 seuls) | Centre-arriere |
| Capteurs (IR, bumpers, cliff, buzzer) | - | **~25g** | Perimetre |
| Jupe TPU confinement | - | **~15g** | Sous chassis |
| Etancheite (joints, presse-etoupes) | - | **~10g** | Plateau |
| Vitre protection camera | - | **~2g** | Support ESP32-CAM |
| Batterie 3S | ~150g | ~150g | Centre (lest pour equilibre) |
| Capot PETG | ~80g | ~80g | Dessus |
| Cables, visserie | ~100g | ~100g | Reparti |
| ~~GoPro + MOD-001~~ | ~~~120g~~ | **0g** (reporte Phase 2) | - |
| **TOTAL** | **~1.4 kg** | **~1.3 kg** | |

Sous les 2.5 kg de budget masse. Marge de 1.2 kg pour Phase 2 (RPi, GPS, LiDAR...).

## 9. Pieces a imprimer (Bambu Lab X1 Carbon)

### Phase 1 (proto fonctionnel) - v1.1

| Piece | Materiau | Qty | Taille estimee | Temps impr. | Changement v1.1 |
|---|---|-----|---|---|---|
| Moyeu roue | PETG noir | 4 | 80x80x25mm | ~1h/pc | = |
| Pneu roue | TPU 95A noir | 4 | 80x80x10mm | ~45min/pc | = |
| Support moteur traction | PETG | 4 | 40x30x25mm | ~30min/pc | = |
| Chariot Z + IMS | PETG | 1 | 120x90x30mm | ~2h | = (logique ressort inversee) |
| Palier lineaire Z | PETG | 2 | 20x20x15mm | ~15min/pc | = |
| ~~Plaque MOD-001 (camera scout)~~ | ~~PETG~~ | ~~1~~ | - | - | **RETIRE** (GoPro reportee) |
| Plaque MOD-002 (brosse) | PETG | 1 | 100x80x20mm | ~30min | = |
| Capot proto | PETG gris | 1 | 200x150x40mm | ~3h | = (+ joints mousse colles) |
| ~~Support GoPro~~ | ~~PETG~~ | ~~1~~ | - | - | **RETIRE** (reportee Phase 2) |
| Support ESP32-CAM | PETG | 1 | 35x30x15mm | ~15min | + logement vitre protection |
| **Jupe confinement brosse** | **TPU 95A** | **1** | **120x100x15mm** | **~45min** | **NOUVEAU** |
| **Support capteurs IR (AV)** | **PETG** | **1** | **60x20x15mm** | **~15min** | **NOUVEAU** |
| **Bumper avant TPU** | **TPU 95A** | **1** | **250x30x10mm** | **~30min** | **NOUVEAU** (integre micro-switch) |
| **Supports cliff (x2)** | **PETG** | **2** | **15x10x10mm** | **~10min/pc** | **NOUVEAU** |
| **Total Phase 1 v1.1** | | **21 pcs** | | **~12-13h** | -2 pieces, +4 pieces |

### Version finale (cf image concept `../specs/concept-forcair-v1.jpg`)

| Piece | Materiau | Qty | Notes |
|---|---|-----|---|
| Plateau | PETG noir | 2-3 pcs assemblees | Remplace le contreplaque |
| **Capot dome** | **PETG bleu translucide** | 1 | Piece maitresse, PCB visibles |
| Habillage lateral | PETG noir | 2 | Cache les profiles, finition lisse |
| Pare-choc avant | TPU noir | 1 | Protection + bumper capteur |
| **Total version finale** | | **+6 pcs** | **~6-8h supplementaires** |

> Filament supplementaire version finale : 1 bobine PETG bleu translucide (~25 EUR).

## 10. Plan de decoupe profiles 2020

```
Barre 1 (1000mm Motedis) :
├── 300mm (longueur G) ──┤── 300mm (longueur D) ──┤── 250mm (traverse AV) ──┤── 150mm reste
                                                                                    │
                                                                              pour Vrillair

Barre 2 (1000mm Motedis) :
├── 250mm (traverse AR) ──┤── 750mm reste pour Vrillair
```

**Forcair consomme seulement 1.1 m de profile** sur les 5m commandes.
Reste 3.9m pour Vrillair Structure S.

## 12. Ordre de montage (v1.1)

### Phase 0 - Validation actionneur (avant toute construction)
0a. Acheter brosses nylon + acier doux perceuse (~10 EUR)
0b. Tester manuellement sur un coin de terrasse (3 types de paves)
0c. Evaluer efficacite ET usure des joints (photos avant/apres)
0d. Valider que moteur Telsa 80 a le couple necessaire
0e. **Decision** : nylon, acier, ou les deux selon la zone

### Phase 1 - Base roulante + scout
1. Couper 4 profiles (300, 300, 250, 250mm)
2. Assembler cadre avec equerres + T-nuts
3. Imprimer 4 supports moteurs (adapter au diam moteurs recup)
4. Fixer supports sous les profiles avec T-nuts
5. Monter moteurs dans supports
6. Imprimer 4 roues (moyeu + pneu)
7. Monter roulements 608ZZ dans moyeux
8. Fixer roues sur axes moteurs (coupleurs)
9. Percer et fixer plateau contreplaque
10. Coller joints mousse adhesive sur le plateau (etancheite capot)
11. Monter presse-etoupes PG7 (4x passages cables plateau)
12. Monter electronique : ESP32-CAM + TB6612FNG + pont diviseur batterie
13. Monter capteurs : 2x IR Sharp (avant) + 2x TCRT5000 cliff (sous-avant)
14. Imprimer et monter bumper TPU avant (integre 2x micro-switch)
15. Imprimer et monter capot + buzzer piezo
16. Appliquer vernis conforme sur ESP32-CAM
17. Firmware : telecommande WiFi + stream video + monitoring batterie
18. **Phase 1 OK** : robot scout telecommande avec detection obstacles

### Phase 1.5 - Nettoyeur semi-autonome (bump & turn)
19. Monter mecanisme Z (tiges lineaires recup + paliers + **ressort vers bas**)
20. Monter MOD-002 (brosse validee Phase 0) sur IMS
21. Imprimer et monter jupe TPU confinement sous chassis
22. Imprimer vitre protection camera (polycarbonate recup)
23. Firmware : bump & turn + detection HSV mousse + brosse ON/OFF + stall detection
24. **Phase 1.5 OK** : robot autonome "Tertill-like" qui brosse la mousse

### Phase 2 - Nettoyeur intelligent
25. Ajouter RPi Zero 2W (SLAM, OWL, cartographie)
26. Ajouter GPS NEO-6M (log des zones traitees)
27. Remonter GoPro sur MOD-001 pour cartographie haute resolution
28. Firmware : navigation systematique ou suivi de joints

### Version finale - Esthetique
29. Imprimer carrosserie PETG noir + capot bleu translucide
30. Habillage lateral + pare-choc TPU definitif
31. (Optionnel) Panneau solaire 5W sur le capot

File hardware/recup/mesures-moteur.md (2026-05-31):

# Recup - Fiche de mesure moteur DC (traction)

> A remplir en desossant les vieilles imprimantes.
> Les cotes mesurees se reportent dans hardware/cad/motor_mount.py
> (le support est parametrique) puis on re-exporte le STL.

## Pourquoi mesurer

`motor_mount.py` part de valeurs par defaut (moteur cylindrique 28 mm x 40 mm).
Tes moteurs recup seront differents. Sans mesure, le berceau ne serrera pas bien.

## Cotes a relever (par moteur)

| Cote | Symbole | Variable motor_mount.py | Moteur A | Moteur B | Moteur C | Moteur D |
|---|---|---|---|---|---|---|
| Diametre corps (mm) | D | MOTOR_DIAMETER | | | | |
| Longueur corps (mm) | L | MOTOR_LENGTH | | | | |
| Diametre axe (mm) | d | (coupleur, pas le mount) | | | | |
| Longueur axe utile (mm) | la | | | | | |
| Tension nominale (V) | U | | | | | |
| Source (imprimante) | | | | | | |

Mesure le diametre au pied a coulisse a 2-3 endroits (les moteurs ne sont pas
parfaitement ronds). Prendre le max.

## Verifications

- [ ] Le moteur tourne (test 5-9 V sur une alim de labo ou pile)
- [ ] Sens de rotation reversible (inverser polarite)
- [ ] Couple a vide correct (pas de point dur)
- [ ] Idealement 4 moteurs identiques (sinon : 2+2, gerer en paires G/D)

## Autres recup utiles a sortir en meme temps

- [ ] Tiges lineaires lisses Ø6 ou Ø8 (axe Z + axes roue) -> mesurer le Ø
- [ ] Ressort de rappel (mecanisme Z, pousse-bas)
- [ ] Coupleurs / pignons (transmission axe moteur -> axe roue Ø8 du 608ZZ)
- [ ] Micro-switchs (bumpers Phase 1)

## Apres mesure

1. Editer motor_mount.py : MOTOR_DIAMETER, MOTOR_LENGTH (+ MOTOR_CLEARANCE si besoin).
2. Re-exporter : `python motor_mount.py` (genere cradle + cap STEP/STL).
3. Imprimer 1 support test, valider le serrage avant de lancer les 4.

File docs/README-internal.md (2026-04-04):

# Forcair - Plateforme Robotique Modulaire d'Exterieur

> Ref : Jayce et les Conquerants de la Lumiere - Forcair (vehicule principal / Armed Force)

Plateforme robotique autonome modulaire pour l'entretien des surfaces pavees.
Base roulante commune + modules outils interchangeables (brosse, camera, spray...).

## Contexte

- Terrain : paves autobloquants + dalles carrees (~150m2 total, comparable a la surface pelouse)
- Probleme : mousse verte dans les joints, mauvaises herbes
- Robot tondeuse existant : Ecovacs Goat 800 RTK (pelouse OK, pas les paves)
- Fabrication : chassis profiles alu 2020 (Motedis) + pieces imprimees 3D (Bambu Lab X1 Carbon)

## Design

Voir document detaille : `hardware/design-v1.md`

### Image concept

Concept Forcair

### Deux versions

| | Proto (Phase 1) | Version finale (Phase 2+) |
|---|---|---|
| Plateau | Contreplaque 5mm | PETG noir imprime |
| Capot | PETG simple (gris) | **PETG bleu translucide** (PCB visibles) |
| Carrosserie | Profiles 2020 apparents | Profiles integres, habillage lisse |
| Cout supp. | - | +25 EUR (bobine PETG bleu translucide) |

### Modules outils (interface standard IMS)

| Ref | Module | Usage | Statut |
|-----|---|---|---|
| MOD-001 | Camera Scout | Cartographie, inspection terrain | Phase 1 |
| MOD-002 | Brosse Rotative | Mousse/herbes dans joints | Phase 2 |
| MOD-003 | Spray | Jet d'eau ou anti-mousse | Futur |
| MOD-004 | Souffleur | Feuilles mortes | Futur |

Changement de module : 2 vis papillon M5, sans outil, en 30 secondes.

### Apercu

```
     300 x 250 x 100 mm, ~1.4 kg

     ┌══profiles 2020══════════════════┐
     │  ┌────────────────────────────┐ │
     │  │  [ESP32-CAM] [RPi Zero 2W]│ │  capot PETG
     │  │  [L298N]     [Batterie 3S]│ │  (waterproof)
     │  ├────────────────────────────┤ │
     │  │  [Axe Z]  [IMS interface] │ │
     │  └────────────┬───────────────┘ │
     └═══════════════╪════════════════─┘
    ◯roue            │brosse         roue◯
                  ▓▓▓▓▓▓▓▓ paves
```

- **Cadre** : 4x profiles alu 2020 (Motedis), equerres aux angles
- **Plateau** : contreplaque 5mm (proto) puis inox recup ou PETG
- **Roues** : 4x 80mm, moyeu PETG + pneu TPU + roulement 608ZZ
- **Traction** : 4WD, moteurs DC recup imprimantes
- **Brosse** : moteur Telsa 80 (12.6V DC) + brosse nylon, sur axe Z lineaire
- **Electronique** : ESP32-CAM + RPi Zero 2W + L298N, tout en stock sauf driver (3 EUR)

## Phases

### Phase 0 - Test actionneur (manuel)
- [ ] Acheter 2-3 brosses nylon/laiton perceuse (Brico, ~10 EUR)
- [ ] Tester manuellement sur un coin de terrasse
- [ ] Evaluer si moteur Telsa 80 ou Fellowes convient
- [ ] Valider quel outil nettoie sans abimer les paves

### Phase 1 - Robot scout + vision
- [x] Tester GoPro Hero 3+ → fonctionnelle
- [x] Identifier electronique → ESP32-CAM + RPi Zero 2W en stock
- [ ] Commander quincaillerie (Motedis + AliExpress)
- [ ] Couper profiles et assembler cadre
- [ ] Demonter imprimantes (moteurs DC + tiges lineaires)
- [ ] Imprimer roues (moyeu PETG + pneu TPU)
- [ ] Imprimer supports moteurs (adapter aux moteurs recup)
- [ ] Assembler base roulante 4WD
- [ ] Cabler ESP32-CAM + L298N + moteurs
- [ ] Pipeline vision : detection mousse par seuillage HSV (OpenCV)
- [ ] Telecommande WiFi depuis Mac/smartphone
- [ ] Cartographie zone a traiter (GoPro montee sur robot)

### Phase 2 - Robot nettoyeur
- [ ] Integrer actionneur valide en Phase 0
- [ ] Monter mecanisme Z (tiges lineaires recup + servo)
- [ ] Asservissement : brosse ON uniquement sur zone verte
- [ ] Boucle fermee : verification apres passage (photo avant/apres)

## BOM

| Piece | Source | Cout |
|---|---|---|
| 4x profiles 2020 (300+300+250+250mm) | Motedis (coupe dans barres 1m) | Inclus commande partagee |
| 4x equerres + fixations | Motedis | Inclus commande partagee |
| Plateau contreplaque 5mm | Brico | ~3 EUR |
| 4x roues (moyeu PETG + pneu TPU) | Impression 3D Bambu Lab | ~4 EUR filament |
| 4x roulements 608ZZ | AliExpress | Inclus commande partagee |
| 4x coupleurs d'arbre | AliExpress | Inclus commande partagee |
| 4x supports moteurs | Impression 3D PETG | ~2 EUR filament |
| 4x moteurs DC traction | Recup imprimantes | 0 EUR |
| Moteur brosse (12.6V DC) | Recup Telsa 80 | 0 EUR |
| Brosse nylon perceuse | Brico | ~5 EUR |
| Mecanisme Z (tiges + paliers) | Recup imprimantes + impression 3D | ~1 EUR |
| ESP32-CAM | Stock (tiroir) | 0 EUR |
| RPi Zero 2W | Stock (tiroir) | 0 EUR |
| GoPro Hero 3+ | Stock | 0 EUR |
| Motor driver L298N | AliExpress | 3 EUR |
| Batterie 3S (18650 recup ou achat) | Recup Ryobi ou achat | 0-15 EUR |
| Capot PETG | Impression 3D | ~3 EUR filament |
| **Total Forcair seul** | | **~10-25 EUR** |
| **+ quote-part quincaillerie partagee** | Motedis + AliExpress | **~40 EUR** |

## Recherche et etat de l'art

Voir document complet : `research/state-of-the-art.md`

Principaux enseignements :
- Brosse rotative validee par la litterature (Rask & Kristoffersen 2007, Cauwer 2014) comme methode la plus efficace sur surfaces dures
- ESP32-CAM suffit pour detection mousse (algo vert-sur-gris inspire de OpenWeedLocator)
- Navigation type Tertill (bump & turn) suffisante pour 30m2
- Gap dans la litterature : aucun papier sur le desherbage autonome robotise sur paves domestiques

## Photos terrain

Voir `specs/photos/` - 8 photos des paves et joints avec mousse.

## Pieces recup + quincaillerie

Voir inventaire et BOM partages : `../depistair/inventory.md`

## Lien entre projets

```
Depistair (recup) ──fournit pieces──▶ Forcair
Vrillair (CNC) ──usine pieces custom──▶ Forcair (supports, plaques)
Blindair (boites) ──range les pieces──▶ Forcair
```

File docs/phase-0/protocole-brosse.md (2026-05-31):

# Phase 0 - Protocole de test brosse (manuel)

> But : valider que le brossage demousse les joints SANS abimer les paves/joints.
> C'est le go/no-go du projet. Tant que ce test n'est pas concluant, le reste
> (robot, vision, navigation) est premature.
> Reference : Rask & Kristoffersen 2007 (R13) identifie l'usure du joint comme
> le risque principal du brossage mecanique.

## 1. Materiel

| Element | Detail |
|---|---|
| Brosse | (a remplir : nylon / acier doux, diametre, forme disque ou coupe) |
| Entrainement | (a remplir : perceuse / visseuse / Dremel / moteur Telsa 80) |
| Vitesse | (a noter si reglable : RPM ou position gachette) |
| EPI | Lunettes obligatoires (projection debris + brins acier), gants |
| Mesure | Telephone (photos) + reglet ou pied a coulisse (profondeur joint) |

## 2. Zones de test

Tester sur plusieurs natures de joint (le terrain en a plusieurs) :

| Zone | Type | Etat mousse initial | Largeur joint |
|---|---|---|---|
| Z1 | Paves autobloquants (terrasse) | | ~10 mm |
| Z2 | Dalles carrees (allee) | | ~8 mm |
| Z3 | (abords piscine, si pertinent) | | |

Choisir des zones DISCRETES (coin peu visible) : le test peut marquer le joint.

## 3. Protocole (par zone)

1. **Photo AVANT** (cadrage net, lumiere naturelle, repere d'echelle si possible).
2. Mesurer/noter la profondeur de mousse dans le joint.
3. Brosser : passe lente et reguliere, pression LEGERE d'abord.
4. **Photo APRES** (meme cadrage que l'avant).
5. Inspecter le joint : mousse residuelle ? sable du joint arrache ? pave raye ?
6. Si mousse residuelle : 2e passe, pression accrue, re-noter.
7. Repeter par zone et par reglage (vitesse / pression).

Photos rangees dans `docs/phase-0/photos/` : `Z1_avant.jpg`, `Z1_apres.jpg`, etc.

## 4. Tableau de releve

| Essai | Zone | Brosse | Vitesse | Pression | Passes | Mousse enlevee (%) | Usure joint | Pave abime | Verdict |
|---|---|---|---|---|---|---|-----|-----|---|
| E1 | Z1 | | | legere | 1 | | none/leger/fort | oui/non | |
| E2 | Z1 | | | moyenne | | | | | |
| E3 | Z2 | | | | | | | | |
| E4 | | | | | | | | | |

Echelle usure joint : none = rien / leger = un peu de sable deplace / fort = joint creuse.

## 5. Criteres de decision

GO si, sur au moins une zone :
- mousse enlevee >= ~80 %,
- usure joint = none ou leger (pas de joint creuse, pas de sable massivement arrache),
- aucun pave raye.

A trancher en fin de test :
- [ ] Brosse retenue : nylon / acier / les deux selon la zone
- [ ] Vitesse cible (pour dimensionner le moteur brosse)
- [ ] Pression cible (valide l'approche ressort-pousse-bas du mecanisme Z, design v1.2 section 8.5)
- [ ] Le moteur Telsa 80 a-t-il le couple necessaire ? (sinon revoir l'actionneur)

## 6. Observations libres

(notes, surprises, idees pendant le test)

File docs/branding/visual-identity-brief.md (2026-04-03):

# Forcair - Brief Identite Visuelle

> A utiliser avec ChatGPT (DALL-E) ou Midjourney pour generer les assets visuels.
> Date : 2026-04-03

## 1. Positionnement

**Forcair** est un robot desherbeur autonome open-source pour paves et terrasses.
Projet DIY, low-cost (~75 EUR), imprime en 3D, electronique recup.

**Cible** : makers, bricoleurs tech-savvy, communaute open hardware, jardiniers geeks.
**Ton** : technique mais accessible, propre, pas "garage sale". Inspire confiance.
**Reference culturelle** : nomme d'apres le vehicule de Jayce et les Conquerants de la Lumiere (annees 80). Clin d'oeil nostalgique, pas retro.

## 2. Direction artistique

### Palette de couleurs

| Role | Couleur | Hex | Reference |
|---|---|-----|---|
| Primaire | Bleu translucide | #4DA6FF | Le capot PETG bleu translucide du robot |
| Secondaire | Gris anthracite | #2D2D2D | Les profiles aluminium 2020 |
| Accent | Vert mousse | #6B8E23 | La mousse = l'ennemi (et l'ecologie) |
| Fond | Blanc casse | #F5F5F0 | Proprete, lisibilite |
| Texte | Noir doux | #1A1A1A | Lisibilite |

### Typographie
- **Titres** : Space Grotesk (Bold) — geometrique, technique, moderne
- **Corps** : Inter — lisible, neutre, universel
- **Code/specs** : JetBrains Mono — standard dev

### Esprit visuel
- Lignes propres, angles nets (comme les profiles 2020)
- Transparence / X-ray (on voit l'interieur, comme le capot bleu translucide)
- Contraste nature (paves, mousse verte) vs tech (alu, PCB, LED)
- Pas de rendu 3D ultra-realiste → plutot style "blueprint technique" ou "photo atelier propre"

## 3. Prompts ChatGPT / DALL-E

### 3.1 Logo principal

```
Prompt DALL-E :
"Minimalist logo for 'Forcair', an open-source autonomous weeding robot.
The logo combines a small wheeled robot silhouette with a circular brush
underneath. Clean geometric lines, inspired by aluminum extrusion profiles.
Color: translucent blue (#4DA6FF) on white background.
Style: flat vector, no gradients, technical/engineering aesthetic.
The robot silhouette should be compact, low-profile, with 4 wheels visible
from a 3/4 top-down view. A subtle circular motion line around the brush
suggests rotation. No text in the image."
```

```
Variante avec texte :
"Same logo as above, with the word 'FORCAIR' in Space Grotesk Bold font
to the right of the icon. Below in smaller text: 'open-source paver weeding robot'.
Translucent blue and dark gray color scheme."
```

### 3.2 Logo icone (favicon / avatar GitHub)

```
Prompt DALL-E :
"Square icon logo for a robotics project called Forcair. A top-down view
of a small square robot with 4 wheels at the corners, seen from above,
with a rotating brush circle visible underneath through a translucent blue
shell. Minimalist, flat vector style, single color: translucent blue on
dark gray background. 512x512px, suitable as GitHub avatar or favicon."
```

### 3.3 Banniere GitHub / Hackaday (1280x640)

```
Prompt DALL-E :
"Wide banner image (2:1 ratio) for an open-source robotics project.
Left side: a close-up photo-realistic render of interlocking concrete pavers
with green moss growing in the joints, outdoor sunlight.
Right side: a clean technical blueprint/schematic of a small 4-wheeled robot
with a rotating brush underneath, drawn in translucent blue lines on dark
gray background. The two halves blend in the middle.
Style: split between nature/problem (left) and tech/solution (right).
Clean, modern, professional. No text."
```

```
Variante avec texte :
"Same split composition. Overlaid text in the center:
'FORCAIR' in large white Space Grotesk Bold,
below: 'Open-Source Autonomous Paver Weeding Robot' in smaller white text.
Below that: small icons for GitHub, 3D printer, ESP32 chip."
```

### 3.4 Photo concept "hero shot"

```
Prompt DALL-E :
"Photo-realistic render of a small autonomous robot on a patio of
interlocking concrete pavers with moss in the joints. The robot is compact
(30x25x10cm), has an aluminum frame made of 20x20mm extrusion profiles,
4 black rubber wheels, and a translucent blue dome shell on top through
which green PCB boards and electronic components are visible inside.
A small rotating brush is visible underneath the robot, actively cleaning
moss from a paver joint. Golden hour outdoor lighting, shallow depth of field.
The surrounding pavers show the contrast between cleaned joints (gray, clean)
and uncleaned joints (green moss). Style: product photography, editorial."
```

### 3.5 Illustration "avant / apres"

```
Prompt DALL-E :
"Split image showing a before/after comparison of concrete interlocking
pavers. Left side labeled 'BEFORE': pavers with heavy green moss growth
in all joints, looking neglected. Right side labeled 'AFTER': same pavers
but joints are perfectly clean, gray, no moss. A subtle translucent blue
robot silhouette is positioned at the dividing line between the two sides,
as if it's cleaning from left to right. Clean, bright, outdoor photography style."
```

### 3.6 Schema technique stylise (pour README)

```
Prompt DALL-E :
"Technical exploded view diagram of a small wheeled robot on a white
background. The robot has 4 layers shown separated vertically:
1. Bottom: 4 wheels with motors on aluminum frame rails
2. Middle: plywood platform with battery and motor driver board
3. Upper: ESP32-CAM module and sensors
4. Top: translucent blue dome cover
Style: technical illustration, isometric view, thin clean lines,
minimal color (blue for dome, green for PCBs, gray for aluminum).
Blueprint aesthetic, numbered callout lines pointing to each component.
No text labels (those will be added later)."
```

## 3.7 IMPORTANT : image concept existante

L'image `specs/concept-forcair-v1.jpg` est deja excellente et definit le ton visuel :
- Robot compact sur paves authentiques
- Capot bleu translucide avec PCB visibles
- Brosse en action sur les joints
- Golden hour, profondeur de champ
- Piscine en arriere-plan (contexte terrasse domestique)

**Utiliser cette image comme reference** dans tous les prompts ChatGPT :
ajouter "Use this reference image for the robot's appearance and visual style"
et uploader l'image en meme temps que le prompt.

Les nouvelles images generees doivent etre **coherentes** avec cette reference.

## 4. Assets a generer (checklist)

| Asset | Format | Usage | Priorite |
|---|---|---|---|
| Logo principal (avec texte) | PNG 1024px + SVG | README, Hackaday, partout | **P0** |
| Logo icone (carre) | PNG 512px | GitHub avatar, favicon | **P0** |
| Banniere (avec texte) | PNG 1280x640 | Header GitHub, Hackaday | **P0** |
| Hero shot (robot sur paves) | PNG 1920px | README, site, reseaux | P1 |
| Avant/apres illustration | PNG 1280px | Hackaday build log Phase 0 | P1 |
| Schema technique eclate | PNG 1920px | README, documentation | P1 |
| Open Graph image | PNG 1200x630 | Apercu liens partages (Slack, Twitter) | P2 |

## 5. Elements textuels de marque

### Tagline (une phrase)
> **"The open-source robot that cleans your patio while you relax."**

### Tagline FR
> **"Le robot open-source qui desherbe vos paves pendant que vous vous reposez."**

### Description courte (README, Hackaday)
> Forcair is a low-cost (<100 EUR), open-source autonomous robot that removes
> moss and weeds from paved surfaces. Built with aluminum extrusion profiles,
> 3D printed parts, and an ESP32-CAM. Named after a vehicle from *Jayce and
> the Wheeled Warriors*.

### Pitch en 3 lignes
> 1. Moss between your pavers? Meet Forcair.
> 2. A 1.3kg autonomous robot with a rotating brush, ESP32 vision, and bump & turn navigation.
> 3. Fully open-source hardware and software. Build yours for under 100 EUR.

## 6. Usage des assets

- **GitHub** : logo icone (avatar) + banniere (social preview) + hero shot (README)
- **Hackaday.io** : logo + banniere + photos relles de build (pas de rendus)
- **Papier HardwareX** : schema technique eclate + photos reelles de tests
- **Reseaux sociaux** : hero shot + avant/apres + tagline

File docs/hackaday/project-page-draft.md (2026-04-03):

# Hackaday.io - Page Projet Forcair (brouillon)

> Ce fichier sert de brouillon pour creer la page projet sur hackaday.io.
> Copier-coller les sections dans le formulaire Hackaday.

## Infos projet

- **Titre** : Forcair - Open-Source Autonomous Paver Weeding Robot
- **URL souhaitee** : hackaday.io/project/XXXXX-forcair
- **Tagline** : A <100 EUR robot that cleans moss from your patio autonomously
- **Statut** : Work in progress

## Tags

`robot`, `esp32`, `esp32-cam`, `weeding`, `3d-printing`, `open-hardware`,
`autonomous`, `opencv`, `cadquery`, `aluminum-extrusion`, `diy`,
`garden-robot`, `paver`, `moss`, `outdoor`, `bump-and-turn`

## Description (Project Details)

### What is Forcair?

Forcair is a small (300x250x100mm, 1.3kg) autonomous robot that patrols
your paver patio and removes moss and weeds from the joints using a
rotating brush. It sees green moss on gray pavers using an ESP32-CAM
(computer vision), navigates with bump & turn (like a Roomba), and costs
under 100 EUR to build.

### Why?

Every spring, moss creeps back between your pavers. You can:
- Spend hours on your knees scraping joints
- Blast with a pressure washer (damages joints, wastes water)
- Spray herbicide (bad for the environment)
- Or let a small robot handle it autonomously

Existing robot mowers work on grass, not pavers. Commercial solutions
don't exist for this niche. So I'm building one.

### How?

- **Frame**: Aluminum 2020 extrusion profiles (Motedis)
- **Wheels**: 4x 80mm, 3D printed (PETG hub + TPU tire)
- **Brain**: ESP32-CAM (camera + WiFi + control, all-in-one)
- **Vision**: HSV green-on-gray detection (inspired by OpenWeedLocator)
- **Navigation**: Bump & turn (IR sensors + bumpers + cliff sensors)
- **Brush**: Rotary nylon or steel wire, on a Z-axis with spring pressure
- **Power**: 3S 18650 battery, ~1h15 autonomy
- **Modular**: Interchangeable tool system (IMS) for future attachments

Everything is open-source: hardware (CERN-OHL-S v2), software (MIT),
CAD files in parametric CadQuery (Python), STL/STEP exports included.

### What makes this different?

I did a full literature review (24 papers, 12+ similar projects). Key finding:
**no one has published an autonomous robotic weeding solution for domestic
paved surfaces**. Agricultural weeding robots exist. Manual paver cleaning
methods are studied. But the intersection is empty.

Forcair fills this gap.

### State of the art

The rotating brush approach is validated by scientific literature:
- Rask & Kristoffersen (2007): brushing is the most effective non-chemical
  method on hard surfaces, 4-6 passes per year are sufficient
- Cauwer et al. (2014): specifically tested on interlocking concrete pavers
- ESP32-CAM can run CNN inference in 7.6ms (Flores et al. 2024)

Full references: see the research/ folder on GitHub.

## Images

1. Concept render (specs/concept-forcair-v1.jpg) - hero image
2. Terrain photos (specs/photos/) - the problem in context
3. Phase 0 results (docs/hackaday/phase-0/) - before/after brush tests

## Composants (Components list sur Hackaday)

Reprendre la BOM du README-community.md.

## Liens

- GitHub : https://github.com/SebE585/forcair
- Licence hardware : CERN-OHL-S v2
- Licence software : MIT

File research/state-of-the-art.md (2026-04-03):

# Forcair - Etat de l'art et recherche bibliographique

> Version : 2026-04-03
> Objectif : alimenter la reflexion technique et preparer un eventuel papier

## 1. Positionnement de Forcair

Forcair est un robot autonome desherbeur de paves, DIY, open-source, budget < 75 EUR.
C'est une niche tres specifique : **desherbage autonome sur surfaces dures** (paves, dalles).

La litterature couvre bien le desherbage agricole (champs) mais tres peu les surfaces urbaines/domestiques.
Les projets DIY existants ciblent presque tous les jardins/potagers.
**C'est une opportunite de contribution originale.**

---

## 2. Projets DIY et open-source similaires

### 2.1 Detection de mauvaises herbes

| Projet | URL | Techno | Reutilisable pour Forcair |
|---|-----|---|---|
| **OpenWeedLocator (OWL)** | [GitHub](https://github.com/geezacoleman/OpenWeedLocator) | RPi + camera, algo vert-sur-brun (ExG/HSV) | **Tres pertinent** : detection mousse verte sur paves gris = cas quasi identique. Publie dans Nature (Scientific Reports). |
| Nindamani / Open Weeding Delta | [GitHub](https://github.com/AutoRoboCulture/Nindamani-the-weed-removal-robot) | Camera + TensorFlow, bras delta imprime 3D | Concept bras delta pour arrachage cible. Trop complexe pour v0.1. |
| Robot solaire Fresnel (Hackaday) | [Hackaday](https://hackaday.com/2023/06/30/gardening-robot-uses-sunlight-to-incinerate-weeds/) | RPi, TF Lite, lentille Fresnel | Pipeline camera → TF Lite → action fonctionnel sur Pi. Approche thermique originale. |

### 2.2 Navigation et plateformes robotiques

| Projet | URL | Techno | Reutilisable pour Forcair |
|---|-----|---|---|
| **LIAM-ESP** | [GitHub](https://github.com/trycoon/liam-esp) | ESP32, GNSS-RTK, ultrasons | Code navigation ESP32 directement reutilisable. Meme plateforme cible. |
| **ESP32 + micro-ROS ultra low-cost** | [Medium (RoboFoundry)](https://robofoundry.medium.com/) | ESP32, micro-ROS, moteurs N20 | Architecture ideale pour Forcair ESP32-only. Tutoriel pas-a-pas. |
| WEEDINATOR | [Hackaday.io](https://hackaday.io/project/204846-weedinator-2026-agricultural-robot) | STM32 + RPi dual-layer | Architecture 2 niveaux (low-level + high-level) bien documentee. |
| Acorn Rover | [GitHub](https://github.com/Twisted-Fields/acorn-precision-farming-rover) | RPi CM4, Python, 4WD, solaire | Schemas PCB KiCad open-source. Architecture logicielle propre. |
| ROMI Rover (H2020) | [Docs](https://docs.romi-project.eu/Rover/hardware/) | RPi 4, moteurs fauteuil roulant | Moteurs recup + doc hardware complete. Modele open-hardware europeen. |
| OSGAR | [GitHub](https://github.com/robotika/osgar) | Python, ROS-independent | Framework leger navigation autonome, tourne sur RPi Zero. |
| FarmBot | [farm.bot](https://farm.bot/) | RPi 3, Arduino Mega, RAMPS | CNC statique, mais code detection mauvaises herbes et communaute enorme. |

### 2.3 Concepts mecaniques et effecteurs

| Projet | URL | Techno | Reutilisable pour Forcair |
|---|-----|---|---|
| **Aigamo Robot** | [GitHub](https://github.com/takespace/aigamo) | Arduino, moteurs DC, palettes rotatives | Perturbation mecanique passive (remuer/brosser) = adapte aux joints. |
| Nellie | [Instructables](https://www.instructables.com/Nellie-the-Weed-Picking-Robot/) | 3x Arduino, camera Pixy, pince servo | Projet DIY tres budget, logique detection + action instructive. |

### 2.4 Produits commerciaux inspirants

| Produit | Concept | Ce qui inspire Forcair |
|---|---|---|
| **Tertill** (discontinue) | Roomba du jardin, solaire, bump & turn, fil coupe | Navigation ultra-simple (bumpers + random walk). Le plus proche de Forcair en philosophie. Discontinue → niche libre. |
| Carbon Robotics LaserWeeder | 8 lasers 150W + IA, 100k herbes/h | Concept destruction thermique ciblee. Version DIY avec petit laser de gravure = piste futur. |
| FarmDroid FD20 | Robot solaire danois, seme + desherbe par GPS | Cartographier les zones "a traiter" vs "a eviter" = applicable a Forcair. |

---

## 3. Papiers scientifiques

### 3.1 Detection par vision / Edge AI

| Ref | Auteurs, Annee | Titre | Venue | Pertinence Forcair |
|-----|---|---|---|---|
| **R01** | Coleman et al., 2022 | OpenWeedLocator (OWL): an open-source, low-cost device for fallow weed detection | Scientific Reports (Nature), 12, 3017 | **Reference** : algo vert-sur-brun sur RPi, open-source. Green-on-brown → green-on-gray pour paves. [DOI](https://doi.org/10.1038/s41598-021-03858-9) |
| **R02** | Flores et al., 2024 | TinyML Classification for Agriculture Objects with ESP32 | MDPI Digital, 5(4) | CNN TFLite sur ESP32-CAM, ~7.6ms inference. Valide la faisabilite ESP32-CAM pour Forcair. |
| R03 | Almadhor et al., 2025 | Optimized embedded AI: efficient implementation of CNNs on ESP32-CAM | Computing (Springer) | Benchmark CNN sur ESP32-CAM : precision proche du haut de gamme, cout 6x inferieur. |
| R04 | Dworak et al., 2024 | Benchmarking Deep Learning Models for Object Detection on Edge Computing Devices | arXiv:2409.16808 | Benchmark YOLOv8/SSD sur RPi 3/4/5 + Edge TPU. SSD MobileNet V1 = 10ms sur RPi 5 + TPU. |
| R05 | Saltik et al., 2025 | Improving Lightweight Weed Detection via Knowledge Distillation | CVPPA @ ICCV 2025 | YOLO11n sur RPi 5 en 105ms. Distillation +2.5% mAP sans alourdissement. |
| R06 | Sapkota et al., 2025 | Star-YOLO: lightweight model for weed detection in cotton fields | Computers and Electronics in Agriculture | Architecture YOLO ultra-legere, techniques d'allegement transferables. |
| R07 | Nair et al., 2025 | Multiclass weed and crop detection using optimized YOLO models on edge devices | Smart Agricultural Technology | Guide selection modele selon compromis precision/vitesse embarquee. |

### 3.2 Navigation autonome low-cost

| Ref | Auteurs, Annee | Titre | Venue | Pertinence Forcair |
|-----|---|---|---|---|
| **R08** | Ellouze et al., 2024 | An Autonomous Irrigation Robot Based on ROS2, YOLOv8 and ESP32 WMN Architecture | IEEE MELECON 2024 | **Architecture de reference** : RPi 4 (vision + SLAM) + ESP32 (moteurs via FreeRTOS/Micro-ROS) + ROS2 Nav2. |
| R09 | Pereira et al., 2025 | Hybrid robot navigation: monocular depth estimation and visual odometry | Computers & Electrical Engineering | Navigation mono-camera low-cost, alternative au LiDAR. Applicable RPi Camera. |
| R10 | Bayode et al., 2025 | Low-cost implementation of an autonomous navigation robot with LiDAR using RPi | ResearchGate | SLAM 2D sur RPi + LiDAR low-cost. Realisable pour un petit robot outdoor. |
| R11 | Singh et al., 2025 | Autonomous navigation of ROS2 based Turtlebot3 using intelligent approach | IJIT (Springer) | RL (TD3, DDPG) sur Turtlebot3, framework reproductible pour la couche navigation. |
| **R12** | 2025 | Novel pavement crack detection sensor using coordinated mobile robots | Transportation Research Part C | Detection fissures/joints chaussees par vision → transposable a la detection des joints de paves. |

### 3.3 Desherbage mecanique et thermique sur surfaces dures

| Ref | Auteurs, Annee | Titre | Venue | Pertinence Forcair |
|-----|---|---|---|---|
| **R13** | Rask & Kristoffersen, 2007 | A review of non-chemical weed control on hard surfaces | Weed Research, 47(5), 370-380 | **Papier de reference** : compare brossage, flambage, eau chaude sur paves. 4-6 brossages/an suffisent. |
| **R14** | Cauwer et al., 2014 | Integrating preventive and curative non-chemical weed control for concrete block pavements | Weed Research, 54(2) | Specifiquement paves autobloquants (= cas Forcair). Preventif + curatif = -50% traitements. |
| R15 | Hansen et al., 2004 | Strategies for non-chemical weed control on public paved areas in Denmark | Pest Management Science, 60(6) | Protocoles et frequences d'intervention validees sur 6 sites danois. |
| R16 | Bauer et al., 2020 | Thermal weed control technologies for conservation agriculture: a review | Weed Research, 60(3) | Temperatures/durees necessaires : >60C pendant quelques secondes. Dimensionnement thermique. |
| R17 | Wie et al., 2024 | Toward Precise Robotic Weed Flaming Using a Mobile Manipulator | arXiv:2407.04929 | Controle de flamme robotisee en exterieur (vent, pression). Adaptable a micro-bruleur. |

### 3.4 Surveys robots desherbeurs

| Ref | Auteurs, Annee | Titre | Venue | Pertinence Forcair |
|-----|---|---|---|---|
| R18 | Hussain et al., 2024 | Recent Advances in Agricultural Robots for Automated Weeding | AgriEngineering (MDPI), 6(3) | Survey complet : detection + action + navigation. Vue d'ensemble. |
| R19 | Xie et al., 2022 | Key technologies of machine vision for weeding robots: a review | Computers and Electronics in Agriculture | Benchmark modeles vision (CNN, YOLO, Faster R-CNN). Cadre theorique. |
| R20 | Gao et al., 2024 | Advances in ground robotic technologies for site-specific weed management | Computers and Electronics in Agriculture | Robots terrestres de precision. Robovator : +18-41% vs manuel. |
| R21 | Li et al., 2025 | Design of autonomous laser weeding robot based on DIN-LW-YOLO | Computers and Electronics in Agriculture | Robot laser + YOLO allege. mAP 88.5%, taux desherbage 92.6%. |
| R22 | Ghatrehsamani et al., 2023 | Robots and shocks: emerging non-herbicide weed control options | NZ J. Crop & Hort. Science | Comparatif cout/efficacite des methodes non-herbicides emergentes. |

### 3.5 Robotique DIY low-cost

| Ref | Auteurs, Annee | Titre | Venue | Pertinence Forcair |
|-----|---|---|---|---|
| R23 | FOSSBot, 2022 | An Open Source and Open Design Educational Robot | Electronics (MDPI), 11(16) | Patterns architecture hardware + logiciel pour robot DIY open-source. |
| R24 | 2016 | Combining Raspberry Pi and Arduino for a low-cost autonomous vehicle | IEEE Consumer Electronics | Papier fondateur architecture dual RPi + Arduino (= RPi + ESP32). |

---

## 4. Analyse : ce que la recherche change pour Forcair

### 4.1 Confirmation des choix actuels

La recherche **valide** les choix du design v1 :

| Choix actuel | Validation |
|---|---|
| Brosse rotative nylon | R13, R14 : le brossage est la methode la plus efficace sur surfaces dures. 4-6 passages/an suffisent. |
| Architecture RPi + ESP32 | R08, R24 : architecture dual-processeur standard et validee pour robots autonomes low-cost. |
| Detection HSV (vert sur fond) | R01 (OWL) : algo ExG/HSV publie dans Nature, fonctionne sur RPi, open-source. Green-on-brown → green-on-gray pour paves. |
| Chassis profile alu + impression 3D | Acorn, ROMI, FOSSBot : pattern standard des robots open-hardware. |
| Budget ~75 EUR | ESP32+ROS2 (RoboFoundry) : robot fonctionnel possible a ce budget. |

### 4.2 Insights qui changent la reflexion

| Insight | Source | Impact sur Forcair |
|---|---|---|
| **Navigation Tertill (bump & turn)** est suffisante pour petite surface | Tertill, Aigamo | Phase 1 : pas besoin de SLAM, bumpers + random walk suffisent pour 30m2. Economise RPi + LiDAR. |
| **ESP32-CAM peut faire du ML** (7.6ms inference CNN) | R02, R03 | Phase 2 : detection mousse possible sur ESP32-CAM seul, sans RPi. Simplifie la BOM. |
| **Preventif + curatif = -50% passages** | R14 (Cauwer) | Ajouter MOD-003 (spray anti-mousse preventif) en complement de MOD-002 (brosse curative). |
| **Detection de joints par vision** est un probleme resolu (fissures) | R12 | Forcair peut suivre les joints au lieu de brosser a l'aveugle → precision + economie d'energie. |
| **4-6 brossages/an suffisent** | R13 (Rask) | Forcair n'a pas besoin d'etre rapide ni endurant. 1h d'autonomie = largement suffisant. |
| **OSGAR** = framework navigation leger sans ROS | OSGAR | Alternative a ROS2 : plus leger, tourne sur RPi Zero. A evaluer. |
| **Micro-ROS sur ESP32** = standard emergent | R08, ESP32+ROS2 | L'ESP32 peut etre un noeud ROS2 natif via micro-ROS. Futur-proof. |

### 4.3 Pistes nouvelles a considerer

| Piste | Source | Faisabilite Forcair | Priorite |
|---|---|---|---|
| Laser de gravure pour desherbage thermique | Carbon Robotics, R21 | Module MOD-006 futur, securite oculaire critique | Basse (v3+) |
| Panneau solaire pour recharge autonome | Tertill, Acorn, FarmDroid | Petit panneau 5W sur le capot, recharge lente entre missions | Moyenne (v2) |
| Cartographie GPS des zones traitees | FarmDroid | ESP32 + module GPS NEO-6M (~3 EUR), log des zones brossees | Moyenne (v2) |
| Suivi de joints par vision (line following) | R12 (crack detection) | ESP32-CAM HSV → detection joints → brossage cible uniquement | **Haute (v1.5)** |
| Mesh WiFi multi-robots | R08 (Ellouze) | 2+ Forcair coordonnes sur grande surface | Basse (v3+) |

---

## 5. Impact sur la BOM

### 5.1 BOM v1 actuelle vs BOM v1.1 (post-recherche)

La recherche suggere des **simplifications** (retirer des composants) et des **ajouts** (composants peu couteux a fort impact).

#### Composants a RETIRER ou REPORTER

| Composant | BOM v1 | Raison du retrait | Economie |
|---|---|---|---|
| RPi Zero 2W | Phase 1 | R02/R03 montrent que l'ESP32-CAM suffit pour la detection HSV et meme du CNN. Reporter a Phase 2 si necessaire. | Simplifie le cablage, l'alim (pas de buck 5V dedie), et le dev logiciel. |
| GoPro Hero 3+ (module MOD-001) | Phase 1 | La camera OV2640 de l'ESP32-CAM suffit pour detection mousse (R01, R02). GoPro = overkill pour Phase 1. | Retire un module, simplifie le design. |

> **Note** : RPi et GoPro restent en stock pour Phase 2 (cartographie haute resolution, SLAM). On ne les jette pas, on les reporte.

#### Composants a AJOUTER

| Composant | Pourquoi | Source | Cout estime |
|---|---|---|---|
| 2x capteurs IR obstacle (GP2Y0A21) | Navigation Tertill-style : detect obstacle a 10-80cm. Plus fiable que bumpers mecaniques seuls. | R08, Tertill, LIAM-ESP | ~2 EUR les 2 (AliExpress) |
| 2x micro-switch bumpers | Detection de contact (murs, bordures). Approche Tertill validee. | Tertill | ~1 EUR les 2 (recup ou achat) |
| Module GPS NEO-6M (optionnel Phase 2) | Log des zones traitees, cartographie. Identifie par FarmDroid comme differentiant. | FarmDroid | ~3 EUR (AliExpress) |
| Buzzer piezo | Retour sonore (batterie faible, obstacle, fin de mission). Standard sur les robots open-source. | FOSSBot, LIAM-ESP | ~0.30 EUR |

#### Composants MODIFIES

| Composant | BOM v1 | BOM v1.1 | Raison |
|---|---|---|---|
| Motor driver | L298N (double pont H) | **TB6612FNG** ou **DRV8833** | L298N chute 2V et chauffe. TB6612/DRV8833 = MOSFET, rendement 95%, plus petit, meme prix (~2-3 EUR). Recommande par la communaute DIY robotique (RoboFoundry, LIAM-ESP). |
| Moteurs traction | 4x DC recup (5-12V) | Garder recup, mais **prevoir fallback N20 200RPM** | R13 (Rask) : le brossage necessite une pression constante → le robot doit avoir du couple. Moteurs recup a tester en Phase 0. |
| Brosse nylon | Disque perceuse ~60mm | **Brosse coupe fil acier doux 50mm** | R13 : les brosses acier sont plus efficaces sur mousse incrustee. Nylon OK pour entretien leger. Acheter les 2 types (~10 EUR total) pour comparatif Phase 0. |

### 5.2 BOM v1.1 revisee

| Piece | Source | Cout | Changement |
|---|---|---|---|
| 4x profiles 2020 (300+300+250+250mm) | Motedis | Inclus commande partagee | = |
| 4x equerres + fixations | Motedis | Inclus commande partagee | = |
| Plateau contreplaque 5mm | Brico | ~3 EUR | = |
| 4x roues (moyeu PETG + pneu TPU) | Impression 3D | ~4 EUR filament | = |
| 4x roulements 608ZZ | AliExpress | Inclus commande partagee | = |
| 4x coupleurs d'arbre | AliExpress | Inclus commande partagee | = |
| 4x supports moteurs | Impression 3D PETG | ~2 EUR filament | = |
| 4x moteurs DC traction | Recup imprimantes | 0 EUR | = (fallback N20 si trop faibles) |
| Moteur brosse (12.6V DC) | Recup Telsa 80 | 0 EUR | = |
| Brosse nylon perceuse | Brico | ~5 EUR | = |
| **+ Brosse acier doux 50mm** | **Brico** | **~5 EUR** | **NOUVEAU (comparatif Phase 0)** |
| Mecanisme Z (tiges + paliers) | Recup + impression 3D | ~1 EUR | = |
| ESP32-CAM | Stock | 0 EUR | = (devient le processeur principal Phase 1) |
| ~~RPi Zero 2W~~ | ~~Stock~~ | ~~0 EUR~~ | **REPORTE Phase 2** |
| ~~GoPro Hero 3+~~ | ~~Stock~~ | ~~0 EUR~~ | **REPORTE Phase 2** |
| Motor driver **TB6612FNG** | AliExpress | ~3 EUR | **REMPLACE L298N** (meilleur rendement) |
| **2x capteurs IR GP2Y0A21** | **AliExpress** | **~2 EUR** | **NOUVEAU** |
| **2x micro-switch bumpers** | **Recup ou achat** | **~1 EUR** | **NOUVEAU** |
| **Buzzer piezo** | **AliExpress** | **~0.30 EUR** | **NOUVEAU** |
| Batterie 3S (18650 recup ou achat) | Recup Ryobi ou achat | 0-15 EUR | = |
| Capot PETG | Impression 3D | ~3 EUR filament | = |
| **Total Forcair v1.1** | | **~15-30 EUR** | **+~8 EUR vs v1, mais plus robuste** |
| **+ quote-part quincaillerie partagee** | Motedis + AliExpress | **~40 EUR** | = |

### 5.3 BOM Phase 2 (ajouts futurs, deja en stock)

| Piece | Source | Cout | Declencheur |
|---|---|---|---|
| RPi Zero 2W | Stock | 0 EUR | Si ESP32-CAM insuffisant pour navigation avancee |
| GoPro Hero 3+ | Stock | 0 EUR | Cartographie haute resolution |
| Module GPS NEO-6M | AliExpress | ~3 EUR | Log zones traitees |
| Panneau solaire 5W | AliExpress | ~8 EUR | Recharge autonome entre missions |
| LiDAR RPLIDAR A1 (ou equiv) | AliExpress | ~20 EUR | SLAM 2D si necessaire (probablement pas pour 30m2) |

### 5.4 Impact sur la masse

| Element | Masse v1 | Masse v1.1 | Delta |
|---|---|---|---|
| Electronique (RPi+ESP32+driver) | ~50g | ~30g (ESP32-CAM + TB6612 seuls) | -20g |
| GoPro + support MOD-001 | ~120g | 0g (reporte) | -120g |
| 2x capteurs IR + bumpers + buzzer | 0g | ~25g | +25g |
| Brosse acier (en plus de nylon) | 0g | ~30g (testee Phase 0, une seule montee) | 0g (choix) |
| **Total** | **~1.4 kg** | **~1.3 kg** | **-115g** |

---

## 6. Architecture logicielle revisee (Phase 1)

La simplification hardware (ESP32-CAM seul) implique une simplification logicielle :

```
     Architecture Phase 1 (simplifiee post-recherche)

     ┌─────────────┐     WiFi      ┌──────────────┐
     │  ESP32-CAM  │◄────────────►│ Mac/Smartphone│
     │             │               │ (monitoring)  │
     │ OV2640 cam  │               └──────────────┘
     │ HSV detect  │
     │ GPIO control│
     └──┬───┬──┬───┘
        │   │  │
   ┌────┘   │  └────────┐
   │        │           │
┌──┴──┐ ┌──┴──┐   ┌────┴────┐
│TB66 │ │Servo│   │IR x2    │
│12FNG│ │ Z   │   │Bumper x2│
│     │ │     │   │Buzzer   │
└┬──┬─┘ └─────┘   └─────────┘
 │  │
4x moteurs DC
```

**Avantage** : un seul firmware a ecrire (ESP32), pas de communication inter-processeurs.
**Algorithme** : OWL simplifie (R01) adapte au vert-sur-gris, directement sur ESP32-CAM.

---

## 7. Strategie de publication (pistes pour papier)

### Angle original identifie

La litterature couvre bien :
- Desherbage agricole robotise (champs, rangs de culture)
- Desherbage thermique/chimique sur surfaces dures (manuellement)

**Gap identifie** : aucun papier ne traite le **desherbage autonome robotise sur surfaces pavees domestiques**.

### Titre de travail

> "Forcair: A Low-Cost Open-Source Autonomous Weeding Robot for Paved Surfaces"

### Contributions potentielles

1. **Adaptation de l'algorithme OWL (green-on-brown) au green-on-gray** pour paves — validation experimentale
2. **Benchmark effecteurs** (brosse nylon vs acier vs thermique) sur paves autobloquants avec metriques quantitatives
3. **Architecture minimale ESP32-CAM only** pour robot de maintenance urbaine < 100 EUR
4. **Protocole d'evaluation** : surface nettoyee/heure, consommation energetique, usure des joints (R13 identifie l'usure comme risque)

### Venues cibles

| Venue | Type | Pourquoi |
|---|---|---|
| HardwareX (Elsevier) | Journal open hardware | Publie des designs open-source reproductibles. OWL y est passe. |
| MDPI Electronics / Robotics | Journal open access | Section DIY robotics, peer-reviewed. |
| Hackaday.io | Communaute | Visibilite + feedback communaute avant soumission journal. |
| IEEE MELECON / ICAR | Conference | Si resultats experimentaux solides. |

---

## 8. References completes

### Projets open-source
- [OWL] https://github.com/geezacoleman/OpenWeedLocator
- [Nindamani] https://github.com/AutoRoboCulture/Nindamani-the-weed-removal-robot
- [Aigamo] https://github.com/takespace/aigamo
- [LIAM-ESP] https://github.com/trycoon/liam-esp
- [Acorn] https://github.com/Twisted-Fields/acorn-precision-farming-rover
- [OSGAR] https://github.com/robotika/osgar
- [FarmBot] https://farm.bot/
- [ROMI] https://docs.romi-project.eu/Rover/hardware/
- [WEEDINATOR] https://hackaday.io/project/204846-weedinator-2026-agricultural-robot
- [Nellie] https://www.instructables.com/Nellie-the-Weed-Picking-Robot/
- [ESP32+ROS2] https://robofoundry.medium.com/

### Papiers scientifiques
- [R01] Coleman et al. (2022). Scientific Reports, 12, 3017. doi:10.1038/s41598-021-03858-9
- [R02] Flores et al. (2024). MDPI Digital, 5(4), 48.
- [R03] Almadhor et al. (2025). Computing (Springer). doi:10.1007/s00607-025-01559-z
- [R04] Dworak et al. (2024). arXiv:2409.16808
- [R05] Saltik et al. (2025). CVPPA @ ICCV 2025. arXiv:2507.12344
- [R06] Sapkota et al. (2025). Computers and Electronics in Agriculture.
- [R07] Nair et al. (2025). Smart Agricultural Technology.
- [R08] Ellouze et al. (2024). IEEE MELECON 2024. doi:10.1109/MELECON.2024.10788325
- [R09] Pereira et al. (2025). Computers & Electrical Engineering.
- [R10] Bayode et al. (2025). ResearchGate/392256188
- [R11] Singh et al. (2025). IJIT (Springer). doi:10.1007/s41870-025-02500-5
- [R12] (2025). Transportation Research Part C.
- [R13] Rask & Kristoffersen (2007). Weed Research, 47(5), 370-380.
- [R14] Cauwer et al. (2014). Weed Research, 54(2).
- [R15] Hansen et al. (2004). Pest Management Science, 60(6).
- [R16] Bauer et al. (2020). Weed Research, 60(3).
- [R17] Wie et al. (2024). arXiv:2407.04929
- [R18] Hussain et al. (2024). AgriEngineering (MDPI), 6(3), 187.
- [R19] Xie et al. (2022). Computers and Electronics in Agriculture.
- [R20] Gao et al. (2024). Computers and Electronics in Agriculture.
- [R21] Li et al. (2025). Computers and Electronics in Agriculture.
- [R22] Ghatrehsamani et al. (2023). NZ J. Crop & Hort. Science.
- [R23] FOSSBot (2022). Electronics (MDPI), 11(16), 2606.
- [R24] (2016). IEEE Consumer Electronics Conference.

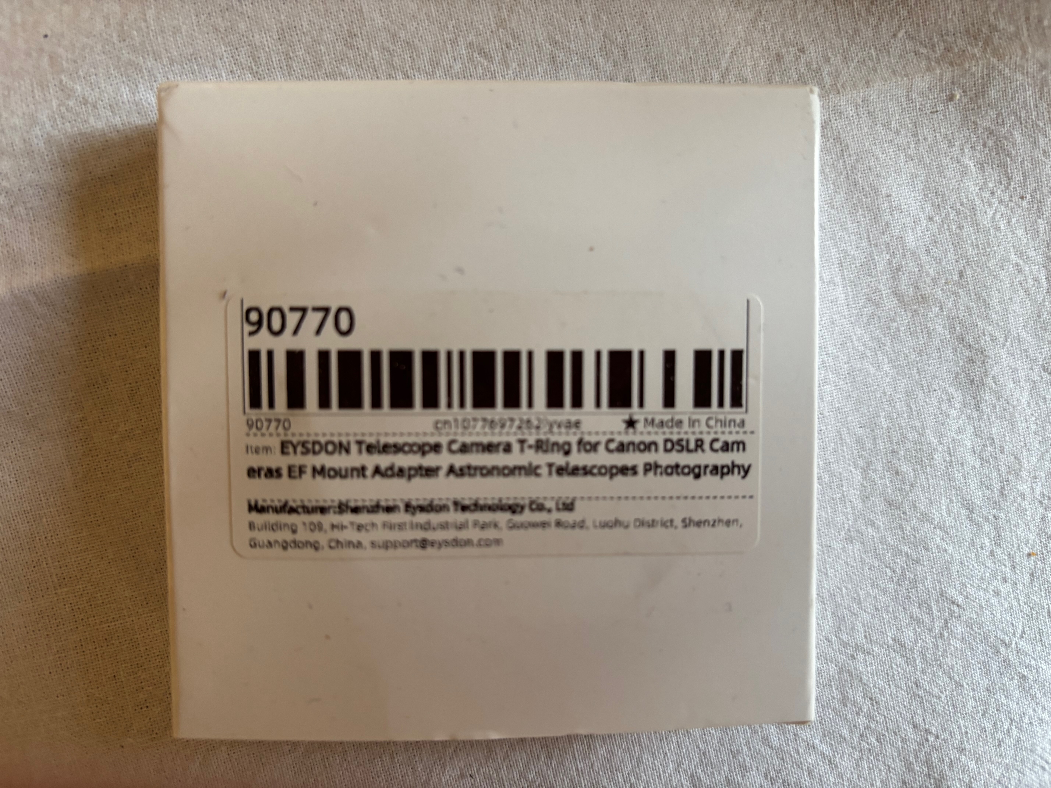
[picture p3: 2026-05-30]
specs/photos/Réception AliExpress/T-Ring Canon.jpeg

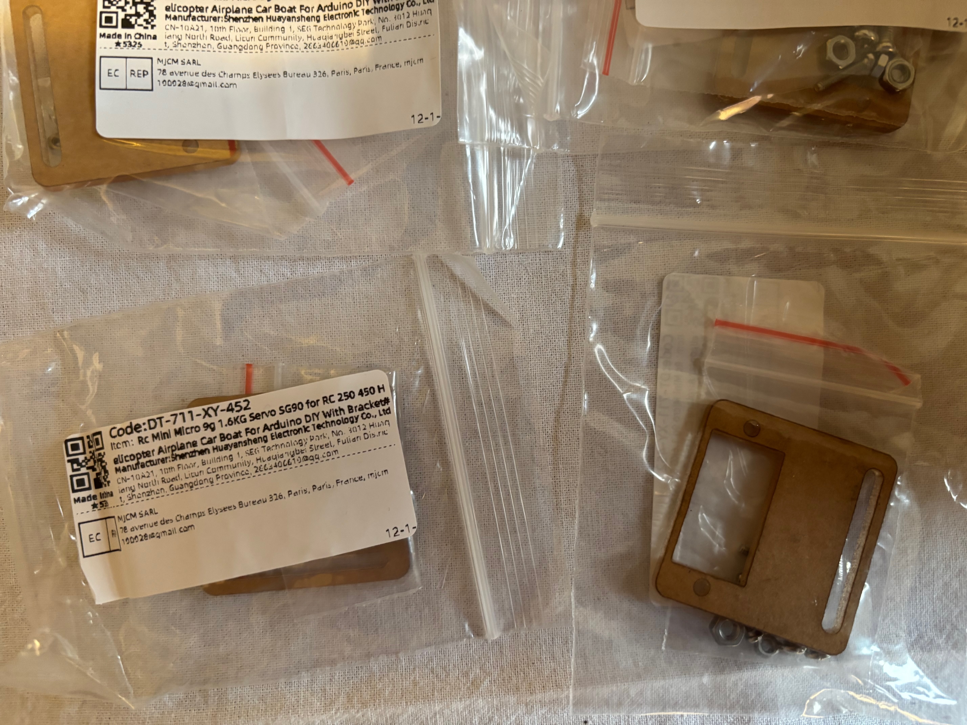
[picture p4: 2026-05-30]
specs/photos/Réception AliExpress/Servo SG90.jpeg

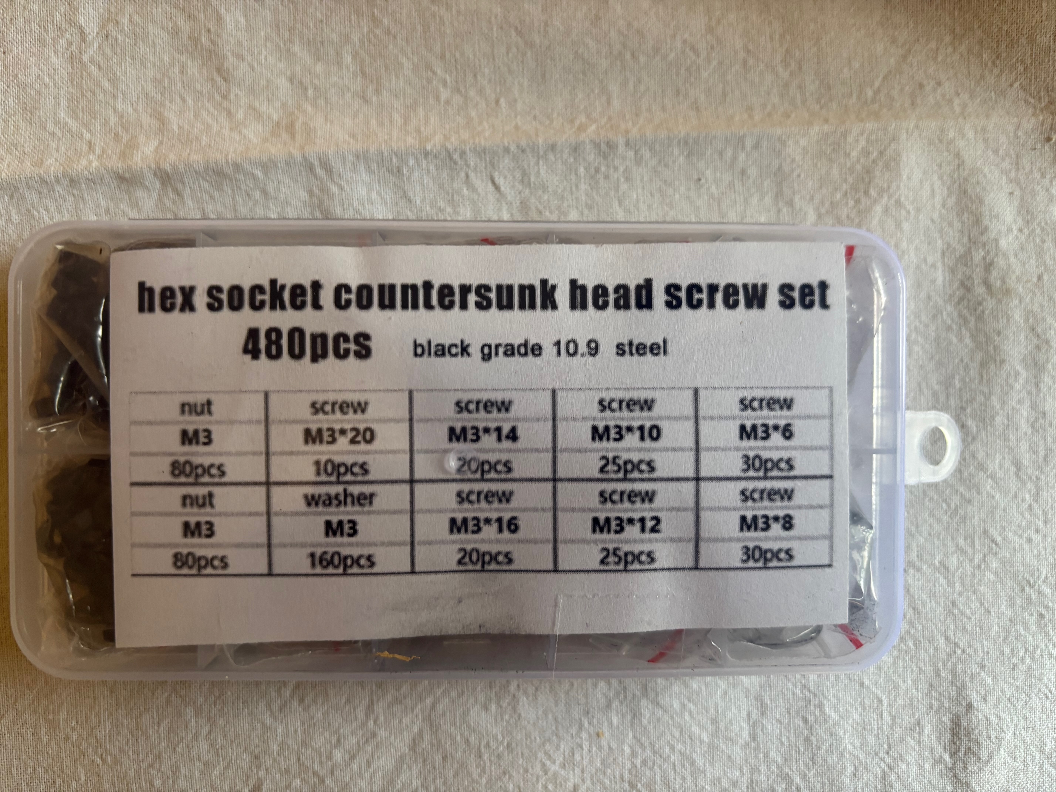
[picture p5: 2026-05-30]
specs/photos/Réception AliExpress/Vis M3.jpeg

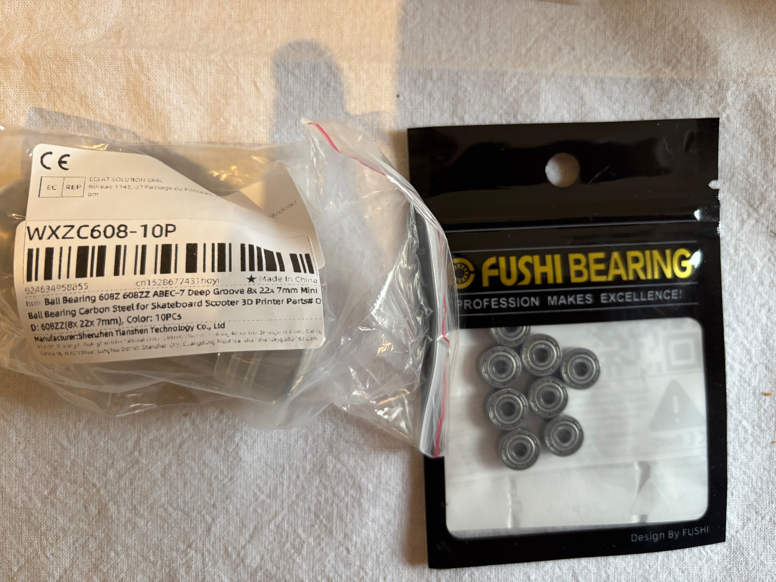
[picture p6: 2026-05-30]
specs/photos/Réception AliExpress/Roulements 608ZZ et 623ZZ.jpeg

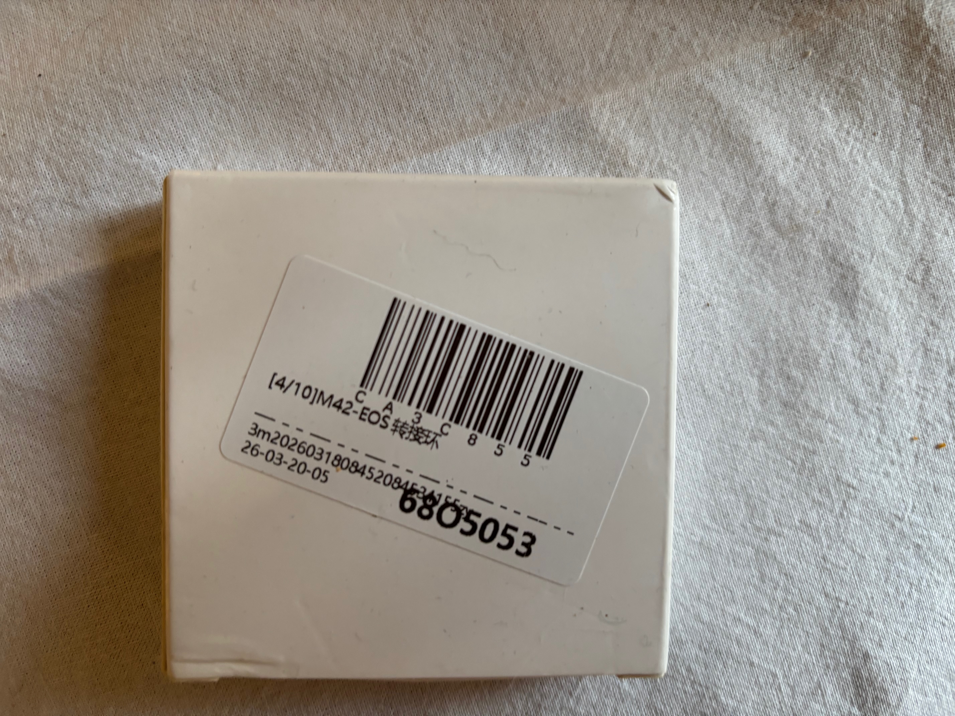
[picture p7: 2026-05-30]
specs/photos/Réception AliExpress/M42 EOS.jpeg

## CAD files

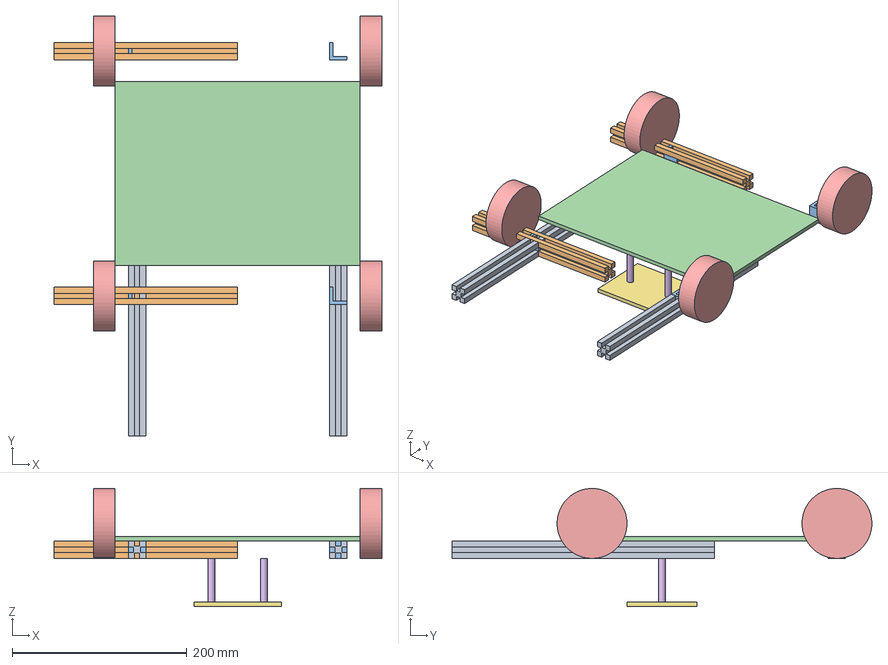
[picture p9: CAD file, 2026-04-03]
hardware/cad/step/assembly_chassis.step
375.0 x 480.0 x 134.9 mm
profil_cote_gauche
profil_cote_droit
profil_face_avant
profil_face_arriere
equerre_0
equerre_1
equerre_2
equerre_3
plateau_base
roue_0
roue_1
roue_2
roue_3
tige_z_gauche
tige_z_droite
platine_ims

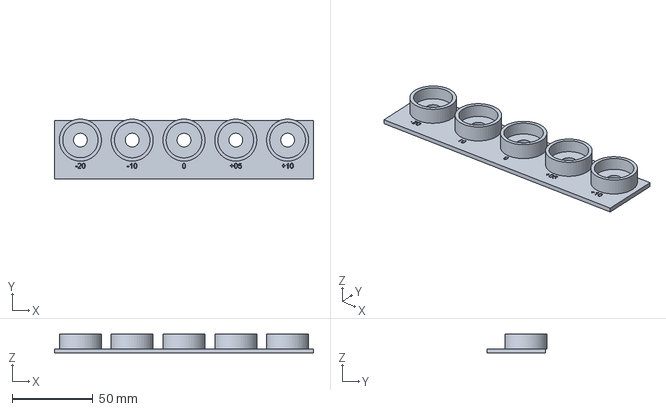
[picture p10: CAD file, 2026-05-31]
hardware/cad/step/FIT-001_bearing_gauge.step
160.0 x 37.0 x 11.5 mm

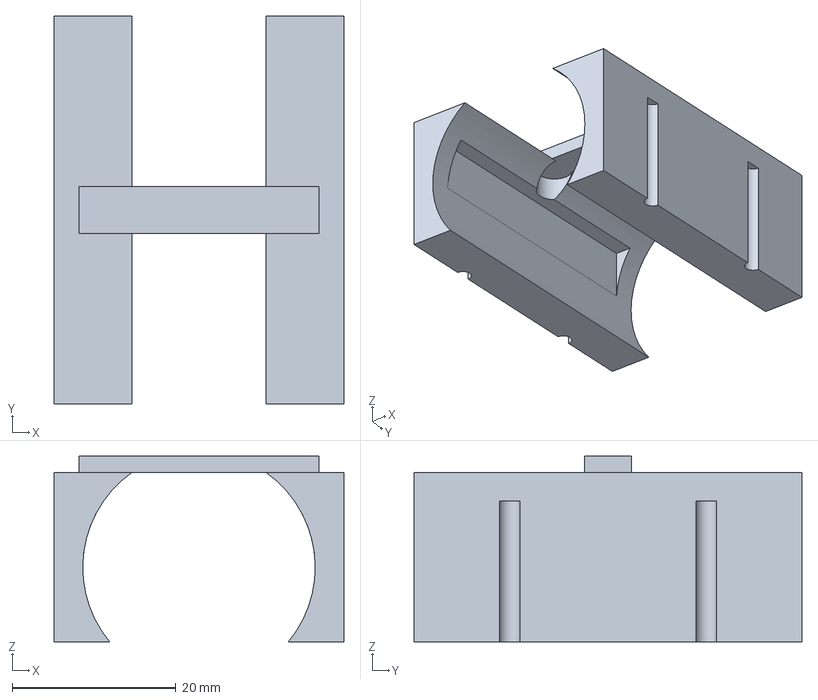
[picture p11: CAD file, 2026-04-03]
hardware/cad/step/motor_mount_cradle.step
35.4 x 47.4 x 22.7 mm

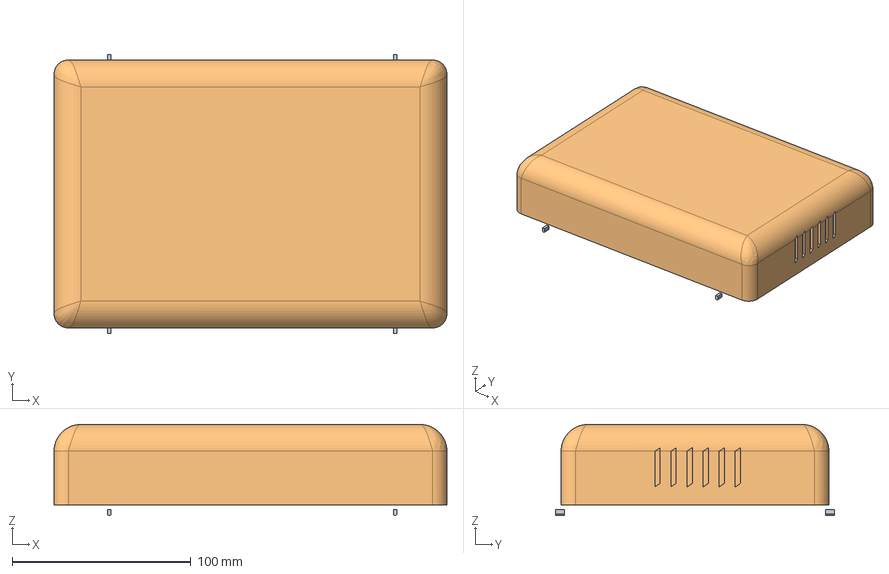
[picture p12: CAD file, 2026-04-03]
hardware/cad/step/capot_dome.step
220.0 x 156.0 x 51.0 mm

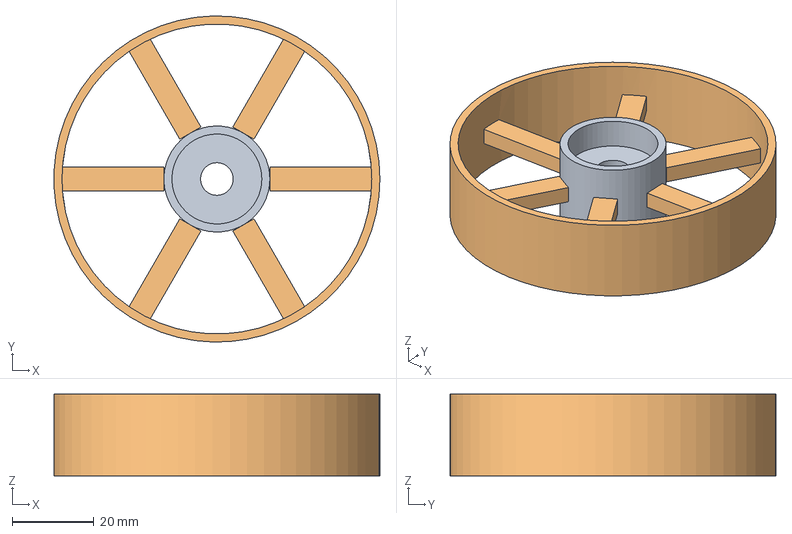
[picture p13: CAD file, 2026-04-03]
hardware/cad/step/WH-001_wheel_hub.step
79.9 x 80.0 x 20.0 mm

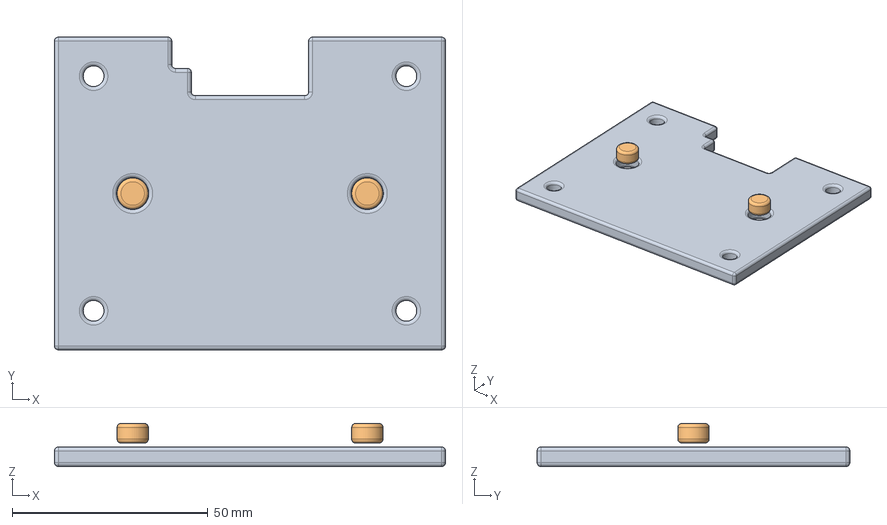
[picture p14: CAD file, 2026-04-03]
hardware/cad/step/ims_plate.step
100.0 x 80.0 x 11.0 mm

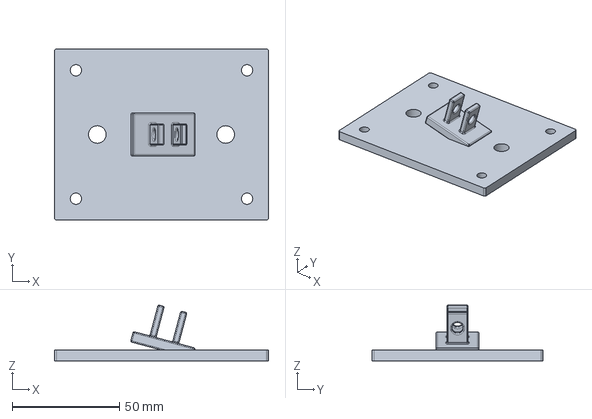
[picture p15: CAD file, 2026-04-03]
hardware/cad/step/mod001_camera_scout.step
100.0 x 80.0 x 26.0 mm

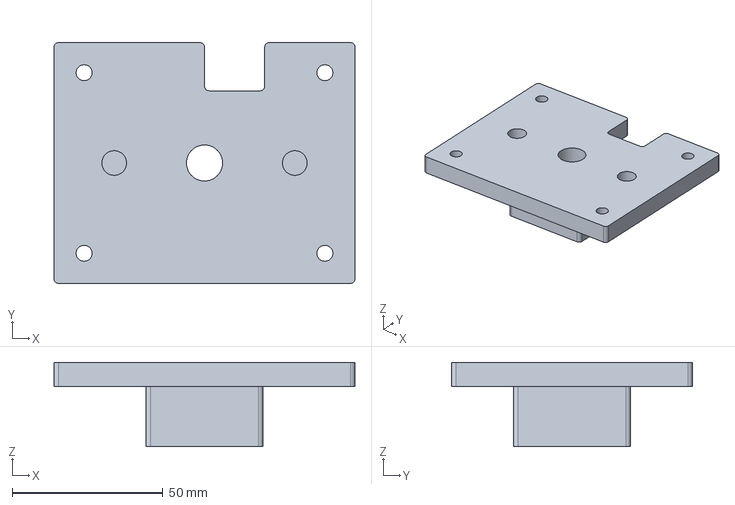
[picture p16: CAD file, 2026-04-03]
hardware/cad/step/mod002_brosse.step
100.0 x 80.0 x 28.0 mm

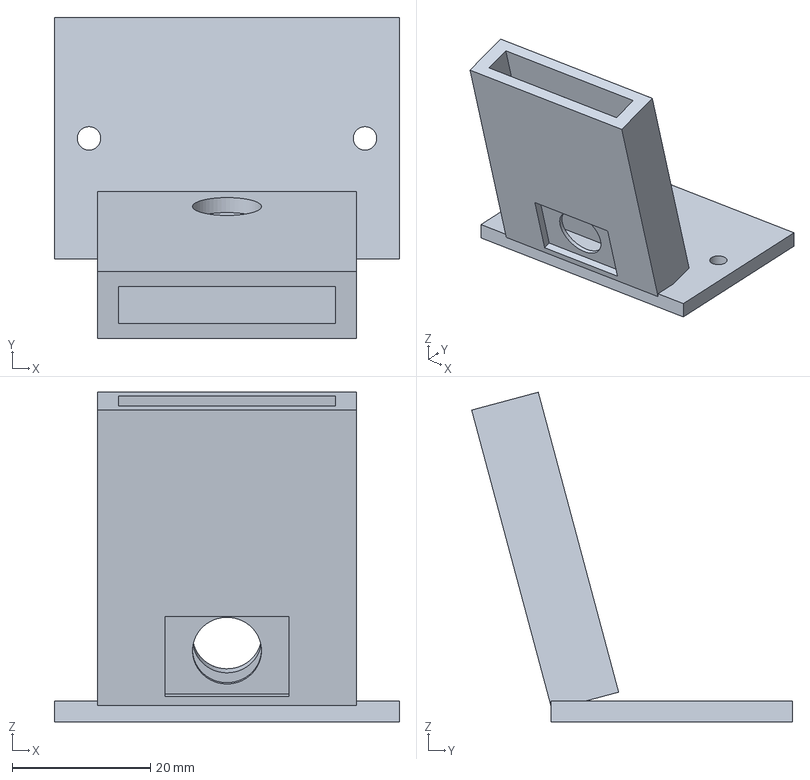
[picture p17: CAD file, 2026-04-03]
hardware/cad/step/esp32_cam_mount.step
50.0 x 46.5 x 47.8 mm

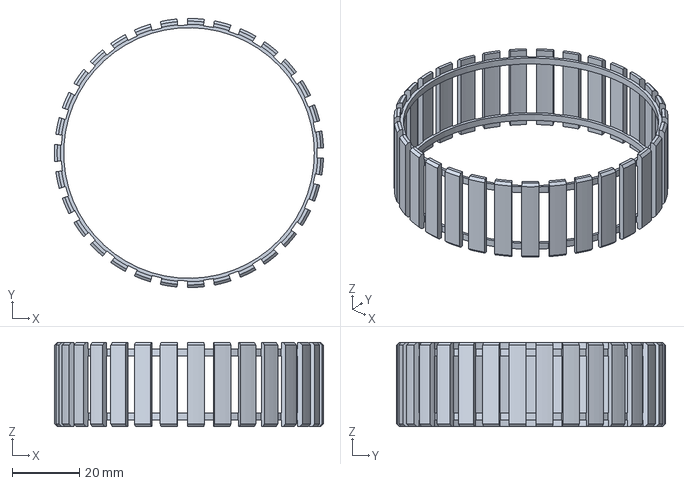
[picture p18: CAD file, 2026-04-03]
hardware/cad/step/WT-001_wheel_tire.step
80.0 x 80.0 x 25.0 mm

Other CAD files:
hardware/cad/stl/FIT-001_bearing_gauge.stl
hardware/cad/stl/WH-001_wheel_hub.stl
hardware/cad/stl/WT-001_wheel_tire.stl
hardware/cad/stl/capot_dome.stl
hardware/cad/stl/esp32_cam_mount.stl
hardware/cad/stl/mod001_camera_scout.stl
hardware/cad/stl/mod002_brosse.stl
hardware/cad/stl/motor_mount_cradle.stl

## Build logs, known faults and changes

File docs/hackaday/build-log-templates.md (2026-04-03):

# Templates Build Logs Hackaday.io

> Les build logs sont des articles de blog courts postes sur la page projet Hackaday.
> Ils documentent chaque etape du projet. C'est le coeur de la communication.
>
> Format : titre accrocheur + texte court (300-800 mots) + photos/videos + lecon apprise.
> Ton : personnel, technique mais accessible, honnete (montrer les echecs aussi).

---

## Build Log #1 : Phase 0 - "Does a brush even work?"

> A poster DES que le test perceuse + brosse est fait.
> C'est le premier contenu, le plus important. Il valide ou invalide tout le projet.

### Titre
**"Phase 0: Testing brush types on 20-year-old pavers (spoiler: it works)"**

### Contenu (adapter apres le test reel)

```markdown
Before building a robot, I needed to answer one question:
**can a rotating brush actually clean moss from paver joints without
destroying them?**

The scientific literature says yes (Rask & Kristoffersen, 2007 - tested
on Danish public pavers). But my pavers are 20 years old with sand joints,
not mortar. Time to test for real.

#### Setup

I grabbed my Bosch drill and two brush attachments from the hardware store:
- Nylon brush disc, 50mm (~5 EUR)
- Soft steel wire brush disc, 50mm (~5 EUR)

I marked 4 test zones (50x50cm each) on my terrace with masking tape
and took photos before each test.

#### Results

[PHOTO: 4 zones avant]

**Zone A - Nylon, 1 pass:**
[PHOTO avant/apres]
[Description des resultats]

**Zone B - Nylon, 3 passes:**
[PHOTO avant/apres]
[Description des resultats]

**Zone C - Steel wire, 1 pass:**
[PHOTO avant/apres]
[Description des resultats]

**Zone D - Steel wire, 3 passes:**
[PHOTO avant/apres]
[Description des resultats]

#### Joint damage assessment

[PHOTO gros plan des joints apres brossage]
[Description : le sable est-il parti ? Les bords du pave sont-ils abimes ?]

#### Motor requirements

With the drill at [X] RPM, the brush needed [light/moderate/heavy] pressure.
This tells me the robot's brush motor needs approximately [X]W and
the spring pressure on the Z-axis should be around [X]g.

My salvaged Tesla 80 motor runs at ~3000 RPM at 12V, which should be
[sufficient/insufficient] based on this test.

#### What I learned

1. [Lesson 1 - e.g. "Steel wire is overkill for regular maintenance,
   but necessary for neglected pavers"]
2. [Lesson 2 - e.g. "The nylon brush doesn't damage sand joints at all"]
3. [Lesson 3 - e.g. "Debris goes everywhere - confirming I need a
   containment skirt on the robot"]

#### What's next

With the brush approach validated, I'm moving to Phase 1: building the
wheeled base. The aluminum 2020 frame parts are ordered from Motedis.

[PHOTO de l'image concept du robot]

Full project details and CAD files on GitHub: [link]
```

### Photos necessaires (checklist)

- [ ] Vue d'ensemble des 4 zones marquees au ruban
- [ ] Les 2 brosses a cote de la perceuse
- [ ] Zone A avant (vue de dessus, meme angle)
- [ ] Zone A apres
- [ ] Zone B avant
- [ ] Zone B apres
- [ ] Zone C avant
- [ ] Zone C apres
- [ ] Zone D avant
- [ ] Zone D apres
- [ ] Gros plan joint apres brossage acier (dommages ?)
- [ ] Gros plan joint apres brossage nylon (dommages ?)
- [ ] Les debris produits (mousse arrachee)
- [ ] Image concept du robot (la belle image generee)

### Conseils photo
- Meme angle et distance pour chaque avant/apres (poser le smartphone sur un support fixe)
- Lumiere naturelle (pas de flash)
- Inclure une reference d'echelle (piece de monnaie, regle)
- Si possible, video courte (10-20s) du brossage en action

---

## Build Log #2 : "Aluminum bones" (assemblage chassis)

### Titre
**"Phase 1.1: Cutting aluminum and assembling the 2020 frame"**

### Structure
```markdown
The Motedis order arrived: [X]m of 2020 aluminum profile, corner brackets,
T-nuts, and hardware.

#### Cutting the profiles

[PHOTO des barres avant decoupe]

Forcair needs 4 pieces: 300mm (x2) + 250mm (x2) = 1.1m total.
I cut them with [scie a metaux / scie circulaire / dremel].

[PHOTO des 4 pieces decoupees]

Tip: [conseil pratique sur la decoupe]

#### Assembly

[PHOTO assemblage etape par etape]

The corner brackets make this trivially easy - no welding, no glue.
Just T-nuts and M4 bolts. The whole frame assembled in [X] minutes.

[PHOTO du cadre assemble, vu de dessus]

#### Weight check

Frame weight: [X]g (budget was 250g).
[Conforme / Ecart et pourquoi]

#### What's next

Printing the wheels and motor mounts. The TPU tires should be interesting...

[PHOTO du cadre a cote de l'image concept]
```

---

## Build Log #3 : "Rolling on custom wheels" (roues + moteurs)

### Titre
**"Phase 1.2: 3D printed wheels and salvaged printer motors"**

### Structure
```markdown
#### Printing the wheels

[PHOTO plateau impression Bambu Lab]

Each wheel is two parts:
- PETG hub with 608ZZ bearing pocket (1h print)
- TPU 95A tire with tread pattern (45min print)

[PHOTO des pieces imprimees]

The TPU tire press-fits onto the PETG hub. Satisfying click.
[VIDEO courte du montage si possible]

#### Salvaging motors

I dismantled a Canon MG6450 and an Epson XP-2150. [PHOTO des imprimantes]

Inside, each printer yielded [X] DC motors, [X] linear rods, and [X] springs.

[PHOTO des moteurs extraits]

Testing each motor: [voltage, RPM, stall current]

#### First roll

[VIDEO du chassis qui roule pour la premiere fois]

It moves! The TPU tires grip well on dry pavers.
On wet pavers: [observation].

#### Issues found

1. [Probleme rencontre et solution]
2. [Autre probleme]
```

---

## Build Log #4 : "It sees green" (vision ESP32-CAM)

### Titre
**"Phase 1.3: ESP32-CAM detects moss with 10 lines of code"**

### Structure
```markdown
The detection algorithm is deliberately simple: if the camera sees
green pixels on gray background, there's moss.

#### The algorithm

Inspired by OpenWeedLocator (OWL), but adapted for pavers:
- OWL detects green-on-brown (soil)
- Forcair detects green-on-gray (pavers)

[CODE snippet du seuillage HSV]

#### Testing on real pavers

[PHOTO vue camera : paves avec mousse, zones detectees en surbrillance]

Detection rate on my terrace: [X]% true positive, [X]% false positive.

The main false positives are: [feuilles, lichen, ombres vertes...]

#### Running on ESP32-CAM

Frame rate: [X] FPS on the ESP32-CAM with OV2640 at QVGA.
[Sufficient/insufficient] for bump & turn navigation.
```

---

## Build Log #5 : "First autonomous run" (bump & turn)

### Titre
**"Phase 1.5: Forcair's first solo patrol on my terrace"**

> C'est LE build log viral. Premiere video du robot autonome.

### Structure
```markdown
[VIDEO 30-60s du robot en action autonome sur la terrasse]

After [X] weeks of building, Forcair completed its first autonomous
patrol of my 30m2 terrace.

#### How it navigates

Bump & turn (inspired by Tertill and Roomba):
1. Drive forward
2. If IR sensor detects obstacle → turn [random angle]
3. If bumper hits → reverse, turn [larger random angle]
4. If cliff sensor triggers → reverse, turn 180 degrees
5. If camera sees green → lower brush, scrub, raise brush, continue

No SLAM, no GPS, no map. Just simple reactive behavior.

#### Coverage test

I let it run for [X] minutes and tracked its path.
[IMAGE ou PHOTO de la couverture]

Coverage result: [X]% of the terrace surface reached.

#### Cleaning effectiveness

[PHOTO avant/apres d'une zone nettoyee par le robot]

Compared to the Phase 0 drill test:
- Robot brush speed: [X] RPM vs drill: [X] RPM
- Cleaning quality: [comparable / needs more passes / better]

#### Battery life

Started at 12.6V, stopped at 9.6V after [X] minutes.
[Conforme a l'estimation de 1h15 ? Pourquoi l'ecart ?]

#### What went wrong

1. [Probleme 1 et comment je l'ai resolu]
2. [Probleme 2]
3. [Probleme 3]

Honest assessment: it works, but [nuances].

#### What's next

[Plans pour ameliorer / Phase 2]
```

---

## Conseils generaux pour les build logs Hackaday

1. **Poster regulierement** (1x/semaine minimum quand actif). La regularite > la perfection.
2. **Montrer les echecs**. La communaute Hackaday respecte l'honnetete. Un echec documente vaut mieux qu'un succes vague.
3. **Photos > texte**. Chaque etape doit avoir au moins 2-3 photos.
4. **Video courte** pour les moments cles (premiere fois que ca roule, premiere detection, premier nettoyage).
5. **Demander du feedback** en fin de post ("What brush type would you try?", "How would you handle the cliff detection?").
6. **Tagger les projets similaires** et mentionner les inspirations. La communaute apprecie la generosite.
7. **Repondre aux commentaires**. Hackaday est une conversation, pas un blog.
8. **Lien vers GitHub** a chaque post pour les gens qui veulent creuser.

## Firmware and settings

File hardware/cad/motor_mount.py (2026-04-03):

#!/usr/bin/env python3
"""
Forcair — Support moteur parametrique pour profil aluminium 2020.

Le support se monte SOUS un profil 2020 (20x20 mm) via 2x ecrous en T M5.
Le moteur DC cylindrique repose dans un berceau en U ; un chapeau superieur
se visse avec 2x vis M3 pour serrer le moteur.
L'axe du moteur est perpendiculaire a la direction du profil (vers l'exterieur
pour le montage de la roue).

Materiau cible : PETG (conges >= 1 mm pour bonne imprimabilite).

Usage :
    python motor_mount.py
    -> genere motor_mount.step et motor_mount.stl dans le meme repertoire.
"""
from __future__ import annotations

from pathlib import Path

import cadquery as cq


# =============================================================================
# Parametres — a adapter selon le moteur recupere
# =============================================================================

# Moteur DC cylindrique
MOTOR_DIAMETER = 28.0       # Diametre exterieur du moteur (mm)
MOTOR_LENGTH = 40.0         # Longueur du corps moteur (mm)
MOTOR_CLEARANCE = 0.4       # Jeu autour du moteur pour insertion facile

# Profil aluminium 2020
PROFILE_WIDTH = 20.0        # Largeur du profil (mm)
PROFILE_SLOT_WIDTH = 6.0    # Largeur de la rainure du profil
PROFILE_SLOT_DEPTH = 6.0    # Profondeur de la rainure (pour centrage)

# Fixation au profil — 2x ecrous en T M5
M5_HOLE_DIA = 5.3           # Percage de passage M5
M5_SPACING = 20.0           # Entraxe des 2 trous M5 (le long du profil)

# Fixation du chapeau — 2x vis M3
M3_HOLE_DIA = 3.4           # Percage de passage M3 (corps)
M3_TAP_DIA = 2.5            # Percage pour taraudage M3 (berceau)
M3_HEAD_DIA = 6.0           # Diametre de la tete fraisee / cylindrique M3
M3_HEAD_DEPTH = 3.5         # Logement de la tete M3

# Epaisseurs de paroi
WALL_THICKNESS = 3.5        # Epaisseur generale des parois
CRADLE_FLOOR = 3.0          # Epaisseur sous le moteur (fond du berceau)

# Imprimabilite
FILLET_RADIUS = 1.0         # Rayon de conge minimum


# =============================================================================
# Dimensions derivees
# =============================================================================

_motor_r = (MOTOR_DIAMETER + MOTOR_CLEARANCE) / 2.0

# Dimensions globales du berceau (partie basse)
CRADLE_WIDTH = MOTOR_DIAMETER + MOTOR_CLEARANCE + 2 * WALL_THICKNESS
CRADLE_DEPTH = MOTOR_LENGTH + MOTOR_CLEARANCE + 2 * WALL_THICKNESS
CRADLE_HEIGHT = _motor_r + CRADLE_FLOOR

# La platine de fixation au profil est au sommet du berceau
PLATE_WIDTH = max(CRADLE_WIDTH, M5_SPACING + M5_HOLE_DIA + 2 * WALL_THICKNESS)
PLATE_DEPTH = CRADLE_DEPTH
PLATE_HEIGHT = WALL_THICKNESS

# Chapeau (clamp superieur)
CAP_WIDTH = CRADLE_WIDTH
CAP_DEPTH = CRADLE_DEPTH
CAP_HEIGHT = _motor_r + WALL_THICKNESS

# Entraxe des vis M3 du chapeau (symetrique en profondeur)
M3_SPACING_DEPTH = MOTOR_LENGTH * 0.6


# =============================================================================
# Fonctions utilitaires d'export (meme patron que blindair/cad/cq/common.py)
# =============================================================================

def export_step(obj: cq.Workplane, path: str) -> None:
    """Exporte un solide CadQuery au format STEP."""
    Path(path).parent.mkdir(parents=True, exist_ok=True)
    cq.exporters.export(obj, path)


def export_stl(obj: cq.Workplane, path: str) -> None:
    """Exporte un solide CadQuery au format STL."""
    Path(path).parent.mkdir(parents=True, exist_ok=True)
    cq.exporters.export(obj, path)


# =============================================================================
# Construction du berceau (partie basse fixee au profil)
# =============================================================================

def build_cradle() -> cq.Workplane:
    """
    Construit le berceau en U + platine de fixation au profil 2020.

    La platine est en haut (contre le profil) ; le berceau pend vers le bas.
    Le moteur est oriente selon l'axe Y (perpendiculaire au profil qui suit X).
    """

    # --- Bloc de base : platine + corps du berceau ---
    total_height = PLATE_HEIGHT + CRADLE_HEIGHT
    part = (
        cq.Workplane("XY")
        .box(PLATE_WIDTH, PLATE_DEPTH, total_height)
    )

    # --- Alésage cylindrique pour le moteur ---
    # Le cylindre moteur est oriente selon Y, centre dans le berceau.
    # Le centre du cylindre est a mi-hauteur du berceau (sous la platine).
    cylinder_center_z = -(PLATE_HEIGHT / 2.0) + (CRADLE_HEIGHT - _motor_r)
    # On perce a travers toute la profondeur
    motor_hole = (
        cq.Workplane("XZ")
        .center(0, -cylinder_center_z)
        .circle(_motor_r)
        .extrude(PLATE_DEPTH / 2.0, both=True)
    )
    part = part.cut(motor_hole)

    # --- Ouverture du U : enlever la matiere au-dessus du moteur ---
    # On decoupe un rectangle au-dessus du cylindre pour creer la forme en U
    cut_width = MOTOR_DIAMETER + MOTOR_CLEARANCE
    cut_height = total_height - PLATE_HEIGHT - (_motor_r - _motor_r * 0.3)
    if cut_height > 0:
        u_cut = (
            cq.Workplane("XY")
            .center(0, 0)
            .rect(cut_width, MOTOR_LENGTH + MOTOR_CLEARANCE)
            .extrude(cut_height)
            .translate((0, 0, total_height / 2.0 - PLATE_HEIGHT - cut_height))
        )
        part = part.cut(u_cut)

    # --- Trous M5 pour fixation au profil (sur la face superieure) ---
    part = (
        part
        .faces(">Z")
        .workplane()
        .pushPoints([(- M5_SPACING / 2.0, 0), (M5_SPACING / 2.0, 0)])
        .hole(M5_HOLE_DIA, PLATE_HEIGHT + CRADLE_FLOOR + 2)
    )

    # --- Ergot de centrage dans la rainure du profil ---
    # Un petit tenon rectangulaire sur la face superieure s'insere dans
    # la rainure du 2020 pour un positionnement precis.
    key_height = 2.0
    key_clearance = 0.3
    key_width = PROFILE_SLOT_WIDTH - key_clearance
    key_length = M5_SPACING + M5_HOLE_DIA + 4
    key = (
        cq.Workplane("XY")
        .box(key_length, key_width, key_height)
        .translate((0, 0, total_height / 2.0 + key_height / 2.0))
    )
    part = part.union(key)

    # --- Trous de vis M3 (taraudage) pour le chapeau ---
    # Places de chaque cote du berceau, traversant les oreilles laterales
    m3_x = CRADLE_WIDTH / 2.0  # au bord des parois laterales
    m3_points = [
        (m3_x, -M3_SPACING_DEPTH / 2.0),
        (m3_x, M3_SPACING_DEPTH / 2.0),
        (-m3_x, -M3_SPACING_DEPTH / 2.0),
        (-m3_x, M3_SPACING_DEPTH / 2.0),
    ]
    # Les trous M3 partent du bas du berceau vers le haut, dans les oreilles
    part = (
        part
        .faces("<Z")
        .workplane()
        .pushPoints(m3_points)
        .hole(M3_TAP_DIA, CRADLE_HEIGHT)
    )

    # --- Conges pour imprimabilite ---
    try:
        part = part.edges("|Y").fillet(FILLET_RADIUS)
    except Exception:
        pass

    return part


# =============================================================================
# Construction du chapeau (clamp superieur)
# =============================================================================

def build_cap() -> cq.Workplane:
    """
    Construit le chapeau qui vient serrer le moteur par le dessous.

    Le chapeau se visse sur le berceau avec 4x vis M3.
    Il contient un demi-cylindre concave qui epouse le moteur.
    """

    part = (
        cq.Workplane("XY")
        .box(CAP_WIDTH, CAP_DEPTH, CAP_HEIGHT)
    )

    # --- Demi-cylindre concave pour le moteur ---
    cap_cyl_z = CAP_HEIGHT / 2.0 - WALL_THICKNESS
    motor_cut = (
        cq.Workplane("XZ")
        .center(0, -cap_cyl_z)
        .circle(_motor_r)
        .extrude(CAP_DEPTH / 2.0, both=True)
    )
    part = part.cut(motor_cut)

    # --- Trous de passage M3 avec logement de tete ---
    m3_x = CRADLE_WIDTH / 2.0
    m3_points = [
        (m3_x, -M3_SPACING_DEPTH / 2.0),
        (m3_x, M3_SPACING_DEPTH / 2.0),
        (-m3_x, -M3_SPACING_DEPTH / 2.0),
        (-m3_x, M3_SPACING_DEPTH / 2.0),
    ]
    part = (
        part
        .faces(">Z")
        .workplane()
        .pushPoints(m3_points)
        .hole(M3_HOLE_DIA, CAP_HEIGHT + 1)
    )

    # Logements de tete M3 (lamages)
    part = (
        part
        .faces(">Z")
        .workplane()
        .pushPoints(m3_points)
        .hole(M3_HEAD_DIA, M3_HEAD_DEPTH)
    )

    # --- Conges pour imprimabilite ---
    try:
        part = part.edges("|Y").fillet(FILLET_RADIUS)
    except Exception:
        pass

    return part


# =============================================================================
# Point d'entree — generation des fichiers
# =============================================================================

if __name__ == "__main__":
    script_dir = str(Path(__file__).resolve().parent)

    print("=== Forcair — Generation du support moteur ===")
    print(f"  Moteur : diam {MOTOR_DIAMETER} mm, long {MOTOR_LENGTH} mm")
    print(f"  Profil : 2020 ({PROFILE_WIDTH}x{PROFILE_WIDTH} mm)")

    # --- Berceau ---
    cradle = build_cradle()
    cradle_step = f"{script_dir}/motor_mount_cradle.step"
    cradle_stl = f"{script_dir}/motor_mount_cradle.stl"
    export_step(cradle, cradle_step)
    export_stl(cradle, cradle_stl)
    print(f"  -> {cradle_step}")
    print(f"  -> {cradle_stl}")

    # --- Chapeau ---
    cap = build_cap()
    cap_step = f"{script_dir}/motor_mount_cap.step"
    cap_stl = f"{script_dir}/motor_mount_cap.stl"
    export_step(cap, cap_step)
    export_stl(cap, cap_stl)
    print(f"  -> {cap_step}")
    print(f"  -> {cap_stl}")

    print("=== Termine ===")

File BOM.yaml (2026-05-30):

# BOM.yaml — Forcair Phase 1.5
# Open hardware autonomous paver weeding robot
#
# This file is consumed by sourcier.shop to auto-generate a BOM widget
# with vendor links optimized per country. Spec: https://sourcier.shop/spec/bom-yaml
#
# Live widget : https://sourcier.shop/bom/SebE585/forcair

project: forcair
version: "1.5"
description:
  fr: Robot autonome de désherbage de pavés open hardware
  en: Open hardware autonomous paver weeding robot
url: https://github.com/SebE585/forcair
license: CERN-OHL-S-2.0
budget_target_eur: 100
budget_realistic_eur: 180
lifecycle: phase_1_achat

items:
  # ── Mécanique structure ─────────────────────────────────────────
  - ref: profil-2020-300
    sourcier_ref: MEC-033
    name:
      fr: Profil aluminium 2020 Type B 4 rainures cut 300mm
      en: Aluminum profile 2020 Type B 4-slot cut 300mm
    qty: 2
    unit: pc
    category: Mécanique - Profilé
    notes:
      fr: Custom cut Motedis (résolution mm). PAS le 2NVS.
      en: Custom cut Motedis (mm resolution). NOT the 2NVS variant.

  - ref: profil-2020-250
    sourcier_ref: MEC-033
    name:
      fr: Profil aluminium 2020 Type B 4 rainures cut 250mm
      en: Aluminum profile 2020 Type B 4-slot cut 250mm
    qty: 2
    unit: pc
    category: Mécanique - Profilé

  - ref: equerre-2020
    sourcier_ref: MEC-031
    name:
      fr: Équerre 2020 B-type rainure 6
      en: Corner bracket 2020 B-type slot 6
    qty: 20
    category: Mécanique - Fixation

  - ref: tnut-m5
    sourcier_ref: MEC-032
    name:
      fr: T-nut M5 rainure 6
      en: M5 T-nut slot 6
    qty: 20
    category: Mécanique - Fixation

  # ── Roues ───────────────────────────────────────────────────────
  - ref: roulement-608zz
    sourcier_ref: MEC-001
    name:
      fr: Roulement 608ZZ ABEC-7
      en: 608ZZ ABEC-7 ball bearing
    qty: 4
    spec: 8x22x7mm
    category: Mécanique - Roulements
    notes:
      fr: Pour les 4 hubs de roue
      en: For the 4 wheel hubs

  - ref: coupleur-5-8
    sourcier_ref: MEC-010
    name:
      fr: Coupleur d'arbre rigide 5mm-8mm
      en: Rigid shaft coupler 5mm-8mm
    qty: 4
    category: Mécanique - Coupleur
    notes:
      fr: Moteur traction → axe roue
      en: Traction motor → wheel axle

  - ref: collier-8mm
    sourcier_ref: MEC-012
    name:
      fr: Collier d'arbre 8mm
      en: 8mm shaft collar
    qty: 8
    category: Mécanique - Fixation

  # ── Cerveau & driver ────────────────────────────────────────────
  - ref: esp32-cam
    sourcier_ref: ELE-002
    name: ESP32-CAM OV2640
    qty: 1
    category: Cerveau
    notes:
      fr: Brain Phase 1 (vision + WiFi + GPIO)
      en: Phase 1 brain (vision + WiFi + GPIO)

  - ref: l298n
    sourcier_ref: ELE-010
    name:
      fr: L298N pont H double
      en: L298N dual H-bridge
    qty: 2
    category: Driver moteur
    notes:
      fr: 4 moteurs traction (2 canaux × 2 modules)
      en: 4 traction motors (2 channels × 2 modules)

  # ── Capteurs Phase 1.5 ──────────────────────────────────────────
  - ref: sharp-ir
    sourcier_ref: ELE-023
    name:
      fr: Sharp GP2Y0A21 capteur IR distance
      en: Sharp GP2Y0A21 IR distance sensor
    qty: 2
    spec: 10-80cm analog
    category: Capteurs Phase 1.5
    notes:
      fr: Détection obstacles avant
      en: Front obstacle detection

  - ref: tcrt5000
    sourcier_ref: ELE-024
    name: TCRT5000 cliff sensor module
    qty: 2
    category: Capteurs Phase 1.5
    notes:
      fr: Détection vide / escaliers sous chassis
      en: Drop detection / stairs under chassis

  - ref: microswitch-bumper
    sourcier_ref: ELE-032
    name:
      fr: Micro-switch à levier snap-action
      en: Snap-action lever microswitch
    qty: 4
    category: Capteurs Phase 1.5
    notes:
      fr: Bumpers avant + 2 spares
      en: Front bumpers + 2 spares

  - ref: buzzer-piezo
    sourcier_ref: ELE-025
    name:
      fr: Buzzer piezo passif
      en: Passive piezo buzzer
    qty: 1
    category: Capteurs Phase 1.5

  # ── Capteur Phase 2 ─────────────────────────────────────────────
  - ref: mpu6050
    sourcier_ref: ELE-030
    name: MPU6050 IMU GY-521
    qty: 1
    category: Capteurs Phase 2
    notes:
      fr: Dead reckoning Phase 2 (substituable par KS0170 du datalogger)
      en: Phase 2 dead reckoning (substitutable with datalogger KS0170)

  # ── Servo brosse ────────────────────────────────────────────────
  - ref: sg90
    sourcier_ref: ELE-021
    name:
      fr: SG90 micro servo 9g 180° with limit
      en: SG90 9g micro servo 180° with limit
    qty: 3
    category: Servo
    notes:
      fr: Brosse Z-axis MOD-002 + spares (PAS variant 360° ni without limit)
      en: Z-axis brush MOD-002 + spares (NOT the 360° or without-limit variant)
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

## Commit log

2026-04-03 init: Forcair open-source autonomous paver weeding robot
    Design v1.1, parametric CAD (CadQuery), state-of-the-art review (24 papers),
    BOM, Hackaday templates, branding brief, CERN-OHL-S v2 + MIT licenses.
    [WH-001_wheel_hub.step, WH-001_wheel_hub.stl, WT-001_wheel_tire.step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]
2026-04-03 add: Sourcier BOM widget link for one-click component sourcing
2026-04-04 fix: surface 30m2 → 150m2, navigation roadmap revised
    Actual paved surface is ~150m2 (same as lawn area), not 30m2.
    This changes the navigation strategy significantly:
    - Phase 1.5: bump & turn by manual zones (~30m2 each)
    - Phase 2: systematic sweep with IMU dead reckoning (MPU6050)
    - Phase 3: GPS RTK (u-blox F9P + NTRIP) for full autonomous coverage
2026-04-11 docs: BOM v4 complete Phase 1+1.5 (MX1508, sensors, power chain, breadboard)
    Replaces the minimal v1 BOM with the real Phase 1.5 functional BOM,
    organized in 5 supply lanes (AliExpress, Motedis, Bambu Lab, Brico,
    reclaimed) plus 3D printed parts.
    New items vs v1 :
    - MX1508 mini motor driver (replaces TB6612FNG in design)
    - TCRT5000 cliff sensor (drop detection)
    - Micro-switches lever (front bumpers)
    - Piezo buzzer (audio feedback)
    - MOSFET IRLZ44N (brush motor switching)
    - Buck MP1584EN (5V from 12V)
    - BMS 3S 25A (18650 protection)
    - MPU6050 IMU (Phase 2 dead reckoning)
    - Breadboard 830 points (proto bench)
    - Bambu Lab filament line (PETG translucent blue + TPU 95A black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
2026-04-11 fix: revert motor driver back to L298N (correct count: 6 pcs in panel)
    The previous commit fc77cf0 mistakenly switched the motor driver from
    TB6612FNG/L298N to MX1508 based on a misread of the receipt photo.
    The actual count was correct after all : 6 L298N modules received as
    an UNCUT PCB panel (3 panels of 2 modules each, separable along the
    V-cut lines). Initial visual count of "3" missed the un-snapped pairs.
    L298N matches the original v3 BOM and the design's pinout assumption
    (PWM EN + IN1/IN2 per channel, 2 channels per module, 2 modules driving
    4 motors in parallel left/right). No design patch required.
    Reverts in this commit :
    - Specifications table : MX1508 → L298N
    - BOM tab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
2026-04-11 feat: BOM.yaml v1 (sourcier.shop standard, multilingue FR/EN)
    27 items consumed by sourcier.shop to auto-generate the BOM widget with
    vendor links optimized per country. Includes sourcier_ref for direct
    lookup, falls back to canonicalize for items without ref.
    Spec : https://sourcier.shop/spec/bom-yaml
    Widget: https://sourcier.shop/bom/SebE585/forcair
2026-04-11 docs: README BOM section now points to sourcier.shop (single source of truth)
    The previous README maintained a verbose BOM duplicated in tables A-F which
    drifted out of sync with the actual hardware needs. Replaced by a clean link
    to the live Sourcier widget which reads BOM.yaml directly from this repo.
    Benefits :
    - BOM.yaml is the single source of truth (machine + human readable)
    - Sourcier widget shows live vendor matches per country (FR/DE/UK/US)
    - Updates to BOM.yaml propagate within 1h via sourcier cache
    - README stays focused on design intent + reclaimed parts (project-specific)
    Also added a clarification on the 75 EUR vs 150 EUR cost discrepancy : the
    banner target assumes all recla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
2026-04-11 docs: realistic cost claims (~150 EUR from scratch, ~75 EUR with reclaim)
    The 4 cost mentions in the README all said 75 EUR / 100 EUR, which only
    holds if you reclaim motors + battery + brush motor + linear rods. Real
    from-scratch cash for Phase 1.5 sits at ~150 EUR (validated by depistair
    tracker: 154.26 EUR for 47 Forcair items including filaments, shipping,
    brico). Both numbers are now shown side by side everywhere.
2026-04-11 docs: fix infill values in printing guide (100% was wrong on wheels)
    - Wheel hubs : 100% -> 40% gyroid + 4 perimeters. Loads are carried by
    the perimeters, infill at 40% is plenty for a 1.3 kg robot
    - TPU tires : 100% -> 20% gyroid. Solid TPU defeats the purpose of TPU
    (compliance). 15-25% gyroid keeps grip + shock absorption
    - Motor mounts : 80% -> 40% gyroid (was overkill for an N20 cradle)
    - Added perimeters + pattern columns and an explanation paragraph
    Total Phase 1 print time : ~12-13h -> ~10-11h
2026-04-11 docs: replace ASCII art with markdown tables and a Mermaid diagram
    - "How It Works" : 3-column ASCII text -> proper markdown table
    - IMS Plate spec : ASCII box -> markdown table with feature/spec/purpose
    - Architecture : ASCII tree -> Mermaid graph LR (renders natively on
    GitHub) + phases 2/3 as plain prose
    The CAD file tree is preserved (it is a legit "tree" output, not art).
2026-04-16 feat(BOM): +8 items manquants — filament 3D (ratio poids), récup ou achat, cerveau Phase 2
    Items ajoutés :
    - RPi Zero 2 WH (cerveau Phase 2, ~26€ Kubii)
    - MicroSD 8-16GB (récupérable)
    - Contreplaqué 5mm 280×230mm (plateau base, ~3€ brico)
    - Joints mousse adhésive (étanchéité capot, ~2€)
    - Tiges lisses 8mm ×2 (récup imprimantes OU ~3€ AE)
    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
2026-04-16 feat(BOM): moteur brosse DC + sourcier_ref sur 10 items
    Ajout moteur-brosse-dc (ELE-042) distinct des N20 traction.
    sourcier_ref assigné : rpi-zero2 (ELE-040), microsd-8gb (ELE-041),
    plateau-cp (MAT-001), joints-mousse (MAT-002), tiges-lisses (MEC-040),
    filament-petg-noir/bleu (FIL-001/002), filament-tpu (FIL-003),
    moteur-brosse-dc (ELE-042), breadboard-830 (ELE-031).
2026-05-30 chore(repo): TODO.md + journal de bord + assets non versionnes
    - TODO.md a la racine : backlog par phase avec estimations (X j) et totaux
    - docs/journal/2026-05-30.md : convention per-project, premiere entree
    - ajout des 6 photos de reception (sous-dossier Reception AliExpress)
    - inclut les modifs en attente de BOM.yaml et design-v1.md (datees 16-17/04)
2026-05-31 feat(phase-0): jauge press-fit 608ZZ + scaffolding tests brosse/moteur
    - bearing_fit_test.py + FIT-001_bearing_gauge (STEP/STL) : barrette 5 coupons
    (poches 21.80 a 22.10) pour calibrer BEARING_PRESS_FIT du moyeu, imprimee PLA
    - docs/phase-0/protocole-brosse.md : protocole test brosse + releve + go/no-go
    - hardware/recup/mesures-moteur.md : cotes a reporter dans motor_mount.py
    - journal 30/05 : session bidouille + point de reprise (mesurer la jauge)
    [FIT-001_bearing_gauge.step, FIT-001_bearing_gauge.stl]
